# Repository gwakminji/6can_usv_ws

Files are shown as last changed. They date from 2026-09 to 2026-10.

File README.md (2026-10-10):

# 🌊 6can
### by Team Eco Bridge AI

> **"우리 동네 호수를 지키는 작은 눈"**
> AI 무인수상정(USV)으로 지역 수질을 실시간으로 관찰하고, 스스로 반응하는 환경 모니터링 시스템

6can은 인천 지역사회의 수질 환경 문제를 해결하기 위해 팀 **Eco Bridge AI**가 진행한
PBL(Problem-Based Learning) 기반 사회공헌 프로젝트입니다. 무인수상정(USV)이 수면을
직접 순찰하며 수질(탁도·pH·용존산소·수온)을 실시간으로 측정하고, 측정값에 따라
정화 펌프를 제어하도록 설계했습니다. 수질과 위치 데이터는 웹 대시보드에 표시됩니다.

## 📷 활동 사진 및 시연 영상

인천 센트럴파크에서 띄운 수상정, 보트 모습, 지역사회 의견 수집 사진입니다. 사진을 누르면 원본을 볼 수 있습니다.

| 인천 센트럴파크에서 띄운 수상정 | 6can 보트 이미지 | 공원·호수에 관한 지역사회 의견판 |
|---|---|---|
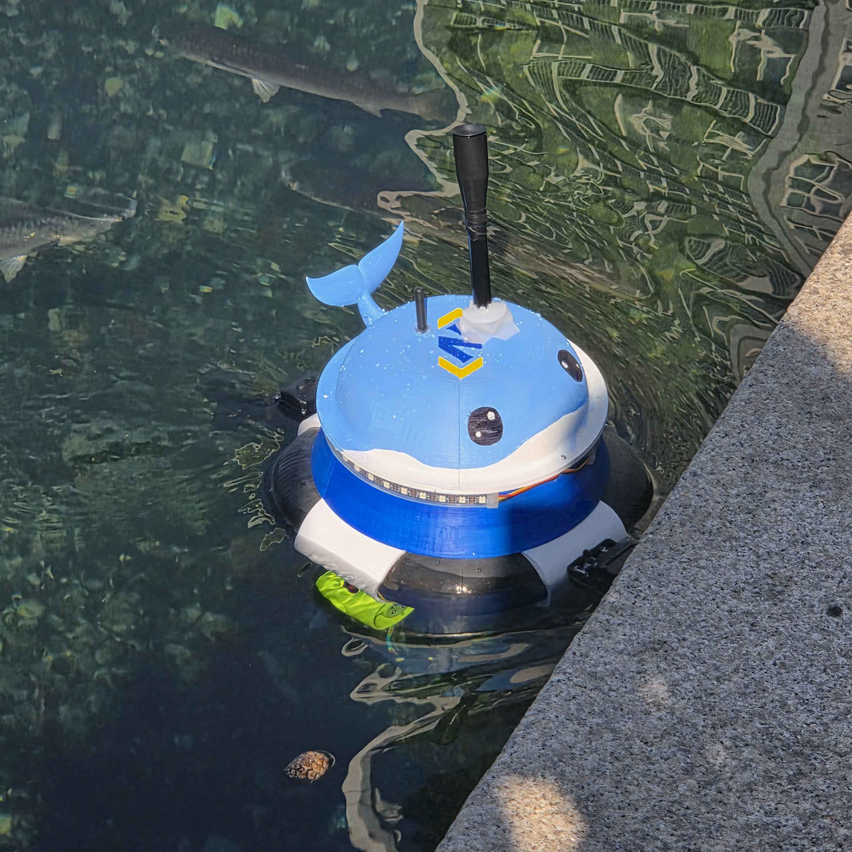
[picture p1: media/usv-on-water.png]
인천 센트럴파크 수면에 떠 있는 파란색 수상정
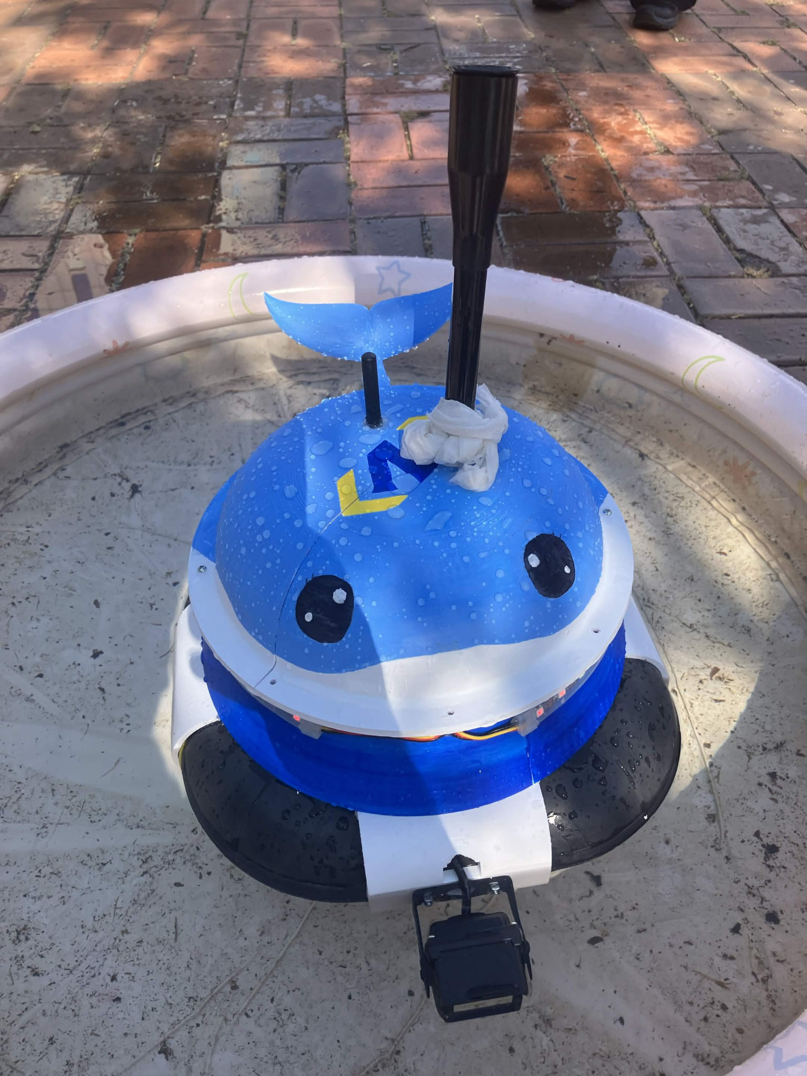
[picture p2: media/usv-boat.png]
파란색 6can 보트의 모습
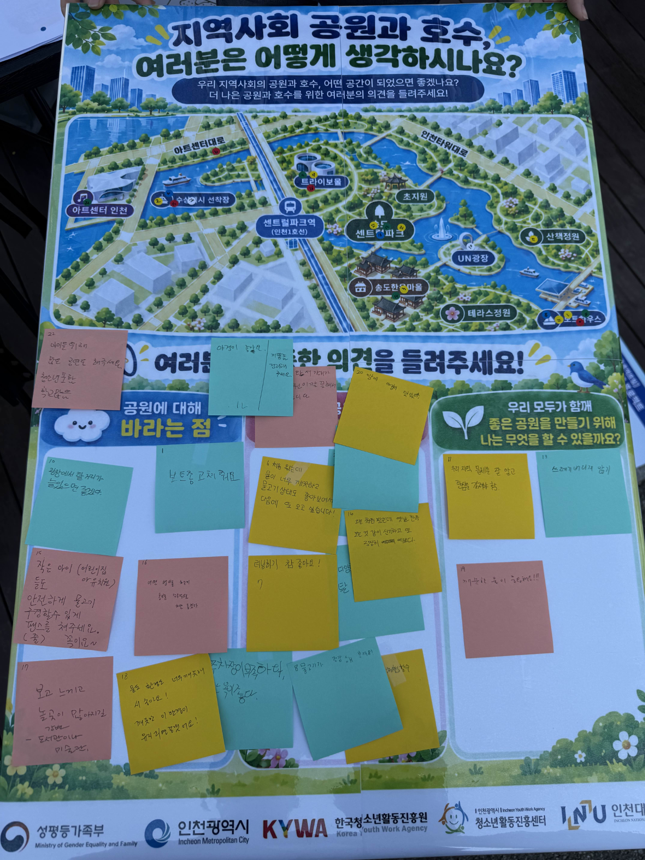
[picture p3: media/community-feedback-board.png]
공원과 호수에 관한 의견이 붙은 게시판
|  |  |  |

**시연 영상:** [인천 센트럴파크에서 수상정이 물을 분사하는 모습 보기 (MP4)](media/usv-water-spray-demo.mp4)

---

## 📌 추진 배경 및 문제 정의

프로젝트는 송도 센트럴파크 호수의 녹조와 부유물 관리 문제를 주제 선정 계기로 삼았습니다.
넓은 수면을 이동하며 수질과 위치를 확인하고, 필요할 때 분수 장치를 작동시키는 방안을 구상했습니다.

인천 지역의 하천·호수는 다음과 같은 구조적인 관리 한계를 안고 있습니다.

| 기존 관리 방식의 한계 | 내용 |
|---|---|
| **낮은 측정 빈도** | 사람이 직접 현장에 나가 정기적으로 샘플을 채취·측정 — 측정 주기 사이의 수질 이상을 놓치기 쉬움 |
| **높은 운영 비용** | 정기 점검마다 인력·출동 비용이 반복적으로 발생 |
| **접근성 사각지대** | 배·선박 없이 접근하기 어려운 구역은 관리 빈도가 더 낮아짐 |
| **시민 체감도 부족** | 수질 데이터가 공개되지 않거나 이해하기 어려운 형태로만 존재해, 환경 문제에 대한 시민 관심으로 이어지기 어려움 |

6can은 이 문제를 "사람이 주기적으로 나가서 재는" 방식에서 "무인선이 상시 관찰하고,
그 결과를 누구나 볼 수 있게 보여주는" 방식으로 바꾸는 것을 목표로 합니다.

---

## 🎯 핵심 목표

- 🌐 **실시간 수질 모니터링** — 탁도, pH, 용존산소, 수온을 무인선이 상시 측정
- 🤖 **자동 반응형 정화** — 측정된 수질 등급에 따라 정화 펌프를 제어하는 기능을 목표로 함
- 🕹️ **원격 조종 지원** — 필요 시 조이스틱으로 무인선을 직접 조종 가능
- 📊 **시민 친화적 시각화** — 웹 대시보드에서 수질 상태와 GPS 미니맵을 확인
- 💸 **저비용 오픈 하드웨어 기반** — 범용 SBC(Arduino UNO Q)·오픈소스 소프트웨어(ROS 2)로 구현해 재현·확장이 쉬운 구조

---

## ⚠️ 작동 특이사항

- 🚤 **배 이동** — 게임 상태와 무관하게 조이스틱으로 항상 조종 가능
- 🔒 **펌프 · 자동/수동 전환 · LED** — 대시보드에서 START를 눌러 게임이 진행 중일 때만 동작 (메인·엔딩 화면에서는 무시됨)
- 🔄 **초기화** — 게임이 시작되거나 끝날 때마다 자동모드는 수동으로, LED는 꺼진 상태로 리셋

---

## 🛠 시스템 아키텍처 및 파트별 역할

6can은 무인선에 탑재되는 **HW(하드웨어 제어) 보드 2대**와, 육상에서 관제하는
**SW/GUI(모니터링·조종) 1대**로 구성됩니다. 보드 간 통신은 ROS 2(DDS)로, 사람이 보는
화면은 웹 브라우저로 분리했습니다.

| 파트 | 보드 | 역할 | 핵심 기술 스택 |
|---|---|---|---|
| 🔧 **HW — 센싱/영상/정화** | B1 (Arduino UNO Q) | 수질·GPS 센서, 수면/수중 카메라, 펌프·LED가 연결된 보드 | ROS 2 Jazzy(Docker), MCU RPC, OpenCV(V4L2), MJPEG |
| 🔧 **HW — 추진** | B2 (Arduino UNO Q) | 추진기만 연결된 별도 보드 | ROS 2 Jazzy(Docker), PWM 모터 드라이버, MCU RPC |
| 💻 **SW/GUI — 관제** | GCS (Raspberry Pi) | 조이스틱 입력 → 조종 명령 변환, 센서/영상 데이터 수신 후 웹 대시보드로 시각화 | ROS 2(네이티브), Python(Flask), HTML5 Canvas, HTTP 폴링·MJPEG 스트리밍 |

**통신 구조**: 보드 사이(B1·B2·GCS)는 ROS 2 DDS 기반 발행/구독(pub-sub)으로 연결되어
있고, GCS는 수신한 최신 상태를 자체 웹 서버(Flask)가 REST 엔드포인트(`/api/state`)로
변환해 브라우저가 200ms 간격으로 폴링합니다. 웹 보트 위치는 `/cmd_vel`에 따라
움직이고 GPS는 미니맵에만 사용됩니다. 카메라 영상은 B1이 MJPEG로 직접 송출해
브라우저가 GCS를 거치지 않고 수신합니다.

**현재 실행 설정 확인 필요:** 펌프·LED는 실제로 B1에 연결돼 있지만,
`actuators.launch.py`는 `actuator_driver_node`를 B2에서 실행합니다. 이 노드는
로컬 MCU RPC를 사용하므로 현재 배선에서 펌프·LED 제어가 가능한지는 확인이 필요합니다.
이번 문서 정리에서는 보드 실행 코드와 자동 실행 스크립트를 변경하지 않았습니다.

### 📡 시스템 구조도

```mermaid
flowchart LR
  JOY([조이스틱]) -->|/joy| J2C
  BROWSER([웹 브라우저 대시보드])
  DIAG[[진단용 · 미구독]]

  subgraph GCS["SW/GUI · Raspberry Pi"]
    J2C[joy_to_cmd_node]
    GUI[gui_main_node]
  end

  subgraph B1S["HW · B1 — 수질·GPS 센서"]
    WQN[water_quality_node]
    GPSN[gps_driver_node]
  end

  subgraph B1C["HW · B1 — 카메라"]
    CAMN[camera_node]
    HVS[http_video_server]
  end

  subgraph B1A["HW · B1 — 실제 펌프·LED 배선"]
    PUMP[펌프·LED MCU]
  end

  subgraph B2["HW · B2 — 실제 추진기 배선 및 현재 실행 설정"]
    THR[thruster_driver_node]
    ACT[actuator_driver_node · 현재 B2에서 실행]
  end

  J2C -->|/cmd_vel| GUI
  J2C -->|/cmd_vel| THR
  J2C -->|/actuator/pump_cmd| GUI
  J2C -->|/actuator/pump_cmd| ACT
  J2C -->|/actuator/auto_mode| GUI
  J2C -->|/actuator/auto_mode| ACT
  GUI -->|/gcs/game_active| J2C
  GUI -->|/actuator/led_cmd| ACT
  ACT -->|/actuator/led_state| GUI

  WQN -->|/water_quality/data| GUI
  WQN -->|/water_quality/data| ACT
  GPSN -->|/gps/fix, /gps/has_fix| GUI
  GPSN -.->|/gps/satellites, /gps/status| DIAG

  CAMN --> HVS
  HVS -. "HTTP :8000 (MJPEG)" .-> BROWSER
  GUI -. "HTTP :8000 (대시보드)" .-> BROWSER

  ACT -->|/actuator/pump_state| GUI
  ACT -.->|로컬 RPC 대상과 실제 배선 불일치 · 확인 필요| PUMP
```

### 🔩 설계 및 실물 하드웨어

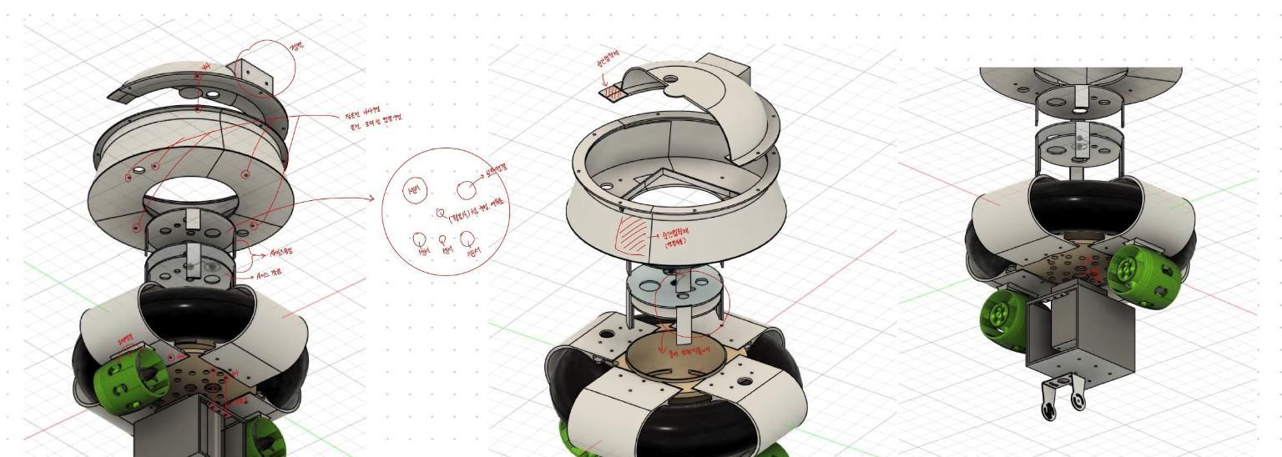
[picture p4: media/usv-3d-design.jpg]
상부 분수 모듈과 구동부를 포함한 수상정 3D 설계 이미지


*수상정 3D 설계 이미지*

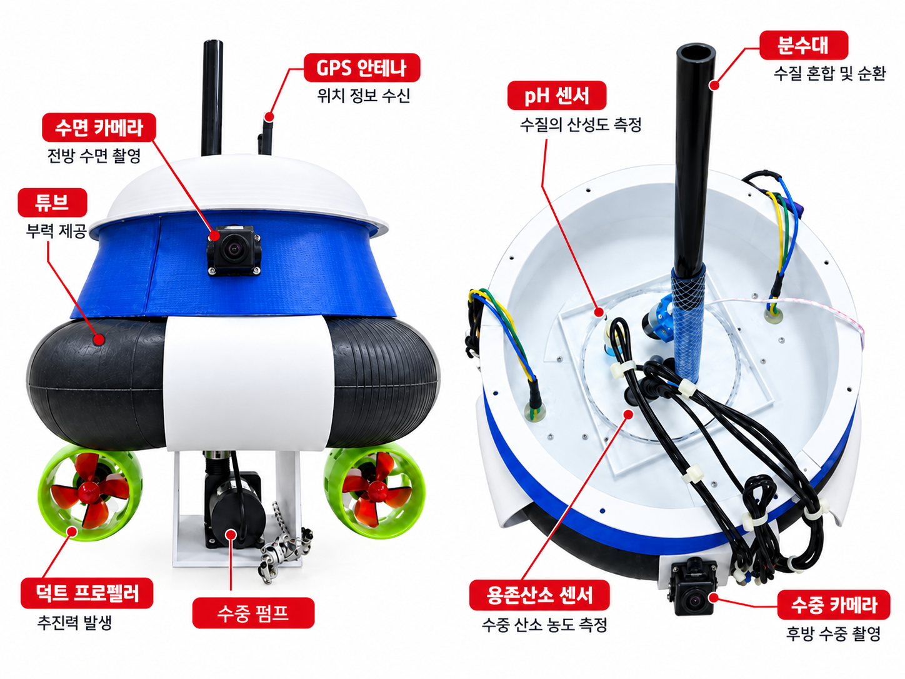
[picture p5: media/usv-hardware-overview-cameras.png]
부력 튜브와 추진기, 펌프, 센서 및 앞쪽 수면 카메라와 뒤쪽 수중 카메라의 위치를 표시한 보트 구성 이미지


---

## 🧪 제작 및 검증 기록

| 단계 | 발표자료에 기록된 내용 |
|---|---|
| 부품 선정 | 교수 자문을 받아 사용 환경과 부품 호환성을 검토 |
| 센서 확인 | 표준용액으로 측정 오차를 확인하고 기준값과 비교 |
| 시스템 통합 | 파트별 작업을 합친 뒤 발생한 호환 문제를 공동 작업으로 점검 |
| 이동성·현장 테스트 | 인천대학교에서 이동성 테스트, 송도 센트럴파크에서 필드 테스트 진행 |

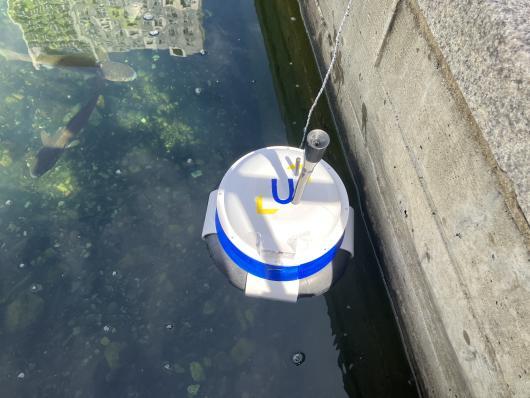
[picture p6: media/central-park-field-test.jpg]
송도 센트럴파크 물 위에 띄운 수상정의 필드 테스트 사진


*송도 센트럴파크 필드 테스트 사진*

---

## 💡 기대 효과

| 효과 | 설명 |
|---|---|
| 🌱 **지역사회 수질 환경 개선** | 상시 순찰형 모니터링으로 수질 이상을 조기에 발견하고, 자동 정화 반응으로 대응 시간을 단축 |
| 💰 **지자체 관리 예산 절감** | 인력 기반 정기 수질 조사의 일부를 무인 자동화로 대체해, 반복적인 출동·인건비 부담을 완화 |
| 📣 **시민 환경 인식 제고** | 그동안 비공개·비정기적이던 수질 데이터를 실시간 시각화로 누구나 접근 가능하게 제공해, 지역 환경 문제에 대한 관심과 참여를 유도 |

---

# 🔧 기술 문서 (개발·운영 가이드)

> 아래는 실제로 이 저장소를 빌드·실행·튜닝할 때 필요한 최소한의 정보만 담았습니다.

## ⚙️ 파라미터 체크리스트 (가장 먼저 확인)

현장/하드웨어가 바뀌면 코드를 고치지 말고 아래 값들만 조정하세요.

| 파라미터 | 위치 | 기본값 | 언제 바꾸나 |
|---|---|---|---|
| `camera_host` | `src/usv_gcs/config/gcs_params.yaml` 또는 `gcs.launch.py` 인자 | `192.168.0.6` (설정 파일 예시) | B1 보드의 실제 IP로 변경 |
| `linear_axis` / `angular_axis` / `angular_scale` | `gcs.launch.py` 인자 | `1` / `0` / `-1.0` | 실제 조이스틱 축 번호·방향이 다를 때 |
| `pump_button` / `auto_button` | `gcs.launch.py` 인자 | `0`(A) / `1`(B) | 조이스틱 버튼 배치가 다를 때 |
| `linear_ramp_rate` / `angular_ramp_rate` | `src/usv_gcs/usv_gcs/joy_to_cmd_node.py`의 `declare_parameter` 기본값 (launch 인자 아님 — 일부러 여기 한 곳만 유지) | `0.2` / `0.4` | 조이스틱을 급히 꺾어도 속도가 얼마나 천천히 올라갈지 조정할 때 |
| `GACHA_GAMEPAD_BUTTON_INDEX` | `dashboard_html.py` 상수 | `2`(Y, 추정치) | 실기기로 검증 후 정확한 값으로 |
| `max_pwm` | `actuators.launch.py` 인자 | `255` | 실제 모터 드라이버 PWM 사양 확정 후 |
| `bad_below` / `good_above` / `*_manual_hold_s` | `actuators.launch.py` 인자 | `40.0` / `60.0` / `60.0`초 | 실측 수질 범위·자동/수동 우선 시간 조정 시 |
| `BACK_GAMEPAD_BUTTON_INDEX` | `dashboard_html.py` 상수 | `8`(추정치) | 실기기로 검증 후 정확한 값으로 |
| `SHOW_SURFACE_CAM` / `SHOW_UNDERWATER_CAM` | `dashboard_html.py` 상단 상수 | `true` / `true` | 수면/수중 카메라 박스를 각각 껐다 켜려면 `false`/`true`로 |
| `surface_device` / `underwater_device` | `camera_streaming.launch.py` 인자 | `/dev/video2` / `/dev/video3` | USB 카메라 재연결로 장치 번호가 바뀌었을 때 (`v4l2-ctl --list-devices`로 확인) |

`dashboard_html.py`처럼 코드 상수를 바꾼 경우, 파일만 고치고 끝이 아니라
**`gui_main_node`를 재시작**해야 브라우저에 반영됩니다 (HTML/JS가 프로세스 시작 시
메모리에 올라가는 구조라서 `--symlink-install`로도 핫리로드는 안 됩니다).

---

## 🚀 실행 방법

```bash
# 1. B1 (센서 + 카메라; 펌프·LED는 B1에 배선됨)
./start_b1.sh

# 2. B2 (추진기; 현재 액추에이터 제어 노드도 함께 시작됨)
cd src/usv_actuators && ./start_actuators.sh

# 3. GCS (관제) — 조이스틱 연결 후
sudo apt install ros-jazzy-joy
colcon build --symlink-install --packages-select usv_gcs
source install/setup.bash
ros2 launch usv_gcs gcs.launch.py
```

브라우저 주소: `http://<GCS_IP>:8000` (GCS에서 열면 `http://localhost:8000`)

B1/B2는 `install_*_autostart.sh`로 부팅 자동 실행을 등록해두면 이후엔 전원만 넣으면
됩니다. 개별 보드 빌드/자동 실행 세부 설정, 컨테이너 구성은 `src/<패키지>/` 아래
`start_*.sh`, `systemd/*.service`를 참고하세요.

---

## 🕹️ 조이스틱 구성

하나의 컨트롤러가 **① 실제 보트 조종(ROS)** 과 **② 웹 대시보드 미니 모니터링 화면
조작(브라우저)** 을 처리합니다. 이동(전진/후진/회전)은 웹 대시보드 상태와 무관하게
항상 되지만, **펌프·자동/수동 전환·LED는 대시보드에서 START를 눌러 게임이 진행 중일
때만** 실제로 동작합니다 (메인 화면·엔딩 화면에서는 버튼을 눌러도 무시됨). 게임이
시작되거나 끝나는 순간마다 자동모드는 수동으로, LED는 꺼진 상태로 초기화됩니다.

| 구분 | 조작 | 동작 |
|---|---|---|
| 보트 조종 (ROS `/joy`) | 왼쪽 스틱 좌/우 · 상/하 | 좌우 회전 · 전진/후진 (`/cmd_vel`) — 게임 상태 무관, 항상 동작 |
| 보트 조종 (ROS `/joy`) | A 버튼 | 펌프 on/off 토글 (게임 진행 중일 때만) |
| 보트 조종 (ROS `/joy`) | B 버튼 | 자동/수동 제어 모드 토글 (게임 진행 중일 때만) |
| 웹 화면 (브라우저 Gamepad API) | Start 버튼 | 대시보드 화면 시작 |
| 웹 화면 (브라우저 Gamepad API) | X 버튼 | LED on/off 토글 (게임 진행 중일 때만) |
| 웹 화면 (브라우저 Gamepad API) | Y 버튼 | 화면 내 상호작용(뽑기) 실행 |
| 웹 화면 (브라우저 Gamepad API) | Back 버튼 | 초기 화면으로 복귀 |

버튼 인덱스를 실기기로 확인하려면 브라우저 콘솔(F12)에서:
```js
setInterval(() => console.log(navigator.getGamepads()[0]?.buttons.map((b,i)=>b.pressed?i:null).filter(v=>v!==null)), 300)
```

---

## 📎 참고

- 인터페이스 계약(토픽 이름/타입), 보드별 상세 빌드 옵션, Docker/systemd 구성은 각
  패키지(`src/usv_sensors`, `src/usv_actuators`, `src/camera_streaming`, `src/usv_gcs`)의
  launch 파일과 스크립트 주석에 정리되어 있습니다.
- 현재 `usv_actuators` 패키지는 추진기 노드와 펌프·LED 제어 노드를 모두 B2에서
  시작합니다. 실제 배선은 B1에 펌프·LED, B2에 추진기만 연결된 구성입니다.

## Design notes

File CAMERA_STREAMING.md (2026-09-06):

# 카메라 스트리밍 (Surface / Underwater) → HTTP:8000

수면(surface) 카메라와 수중(underwater) 카메라 영상을 ROS 2 토픽으로 발행하고,
HTTP MJPEG 스트림으로 변환해 내보내는 파이프라인입니다. 브라우저 UI(화면
구성)는 이 프로젝트의 범위가 아니며, 스트림 URL을 제공하는 데까지만 다룹니다.

전부 **자체 작성한 가벼운 Python/OpenCV 코드**로 만들었습니다 (`usb_cam`,
`web_video_server` ROS 패키지는 쓰지 않습니다 — 두 패키지가 boost-dev,
ffmpeg-dev, GTK/Qt 등을 끌고 와서 이 보드(9.8GB 디스크)에서는 이미지 빌드가
디스크 부족으로 계속 실패했습니다. 대신 `opencv-python-headless`(pip, GUI
의존성 없음) 하나만 써서 이미지 용량을 947MB → 1.1GB 수준으로 유지했습니다).

## 아키텍처

```text
surface 카메라(USB) ──┐
                      ├─ camera_node(OpenCV) ──▶ /camera/surface/image_raw ────┐
underwater 카메라(USB)┘                          /camera/underwater/image_raw ─┤
                                                                                ▼
                                                                  http_video_server
                                                              http://<보드IP>:8000
```

- `camera_node`가 `cv2.VideoCapture`로 두 카메라를 열어 `sensor_msgs/msg/Image`를
  초당 15프레임(기본값)으로 계속 발행합니다. (정지 이미지 한 장이 아니라
  연속 프레임 스트림입니다.) 카메라가 없거나 열기 실패하면 죽지 않고 계속
  재시도만 합니다.
- `http_video_server`가 그 두 토픽을 구독해 `cv2.imencode`로 JPEG 변환 후,
  Python 표준 `http.server`로 MJPEG(`multipart/x-mixed-replace`) 스트림을
  내보냅니다.
- ROS 2 Jazzy는 UNO Q Linux 위 **별도의** Docker 컨테이너
  (`camera_streaming_container`, 이미지 `camera_streaming_image`)에서 실행됩니다.
  같은 B1 보드에서 도는 수질/GPS 컨테이너(`usv_sensors_container` / `usv_sensors_image`)와
  이름이 완전히 분리되어 있어 서로 절대 충돌하지 않습니다. `--network host`라서
  컨테이너 안에서 연 포트가 보드의 실제 포트로 바로 노출되고, 같은
  `ROS_DOMAIN_ID=0`을 쓰므로 두 컨테이너의 ROS 2 토픽은 호스트 네트워크
  위에서 서로 정상적으로 보입니다(간섭 없이 공존). B1 보드를 통째로 올릴 땐
  레포 루트의 `start_b1.sh`가 이 컨테이너와 `usv_sensors` 컨테이너를 순서대로
  띄운다 (README.md 3항 참고).

## 패키지 위치

```text
6can_usv_ws/src/camera_streaming/
├── Dockerfile
├── requirements.txt            # opencv-python-headless, numpy
├── start_camera_streaming.sh   # 이미지 빌드(최초 1회) → 컨테이너 실행
├── install_autostart.sh        # (선택) 부팅 시 자동 실행 등록 (systemd/camera-streaming.service)
├── package.xml
├── setup.py / setup.cfg
├── camera_streaming/
│   ├── camera_node.py         # OpenCV 캡처 → ROS 2 Image 발행
│   └── http_video_server.py   # ROS 2 Image 구독 → HTTP MJPEG
└── launch/camera_streaming.launch.py
```

## ROS 2 토픽

| 토픽 | 타입 | 설명 |
|---|---|---|
| `/camera/surface/image_raw` | `sensor_msgs/msg/Image` | 표면 카메라 원본 프레임 (bgr8) |
| `/camera/underwater/image_raw` | `sensor_msgs/msg/Image` | 수중 카메라 원본 프레임 (bgr8) |

## HTTP 엔드포인트 (기본 포트 8000)

| URL | 설명 |
|---|---|
| `http://<보드IP>:8000/` | 현재 스트리밍 가능한 토픽 목록 페이지 |
| `http://<보드IP>:8000/stream?topic=/camera/surface/image_raw` | 표면 카메라 **실시간 영상** (MJPEG, `<img>` 태그로 그대로 재생됨) |
| `http://<보드IP>:8000/stream?topic=/camera/underwater/image_raw` | 수중 카메라 **실시간 영상** |
| `http://<보드IP>:8000/snapshot?topic=/camera/surface/image_raw` | 표면 카메라 정지 이미지 한 장(jpeg) |
| `http://<보드IP>:8000/snapshot?topic=/camera/underwater/image_raw` | 수중 카메라 정지 이미지 한 장(jpeg) |

화면을 여러 개 동시에 띄우고 싶으면 `<img src="...">` 태그를 토픽별로 나란히
두면 됩니다. 서버가 커넥션마다 별도 스레드로 처리해서 동시 스트리밍에
문제없습니다.

```html
<img src="http://<보드IP>:8000/stream?topic=/camera/surface/image_raw">
<img src="http://<보드IP>:8000/stream?topic=/camera/underwater/image_raw">
```

## launch 인자 (기본값)

| 이름 | 기본값 | 설명 |
|---|---|---|
| `surface_device` | `/dev/video2` | 표면 카메라 V4L2 장치 경로 |
| `underwater_device` | `/dev/video3` | 수중 카메라 V4L2 장치 경로 |
| `port` | `8000` | HTTP 포트 |

기본값 `/dev/video2`, `/dev/video3`는 보드 내장 Venus 인코더/디코더가 이미
`/dev/video0`, `/dev/video1`을 쓰고 있어서 USB 카메라가 보통 2번부터 잡힐
것이라는 **예상값**입니다.

## 실제 USB 카메라 연결 후 할 일

1. 카메라 2대를 **UNO Q 보드**의 USB 포트에 연결합니다 (노트북이 아니라 보드에
   꽂아야 이 파이프라인이 잡을 수 있습니다).
2. 실제로 잡힌 장치 번호를 확인합니다.
   ```bash
   v4l2-ctl --list-devices
   ```
3. 기본값(`/dev/video2`, `/dev/video3`)과 다르면 `start_camera_streaming.sh`가
   실행하는 `ros2 launch` 줄에 인자를 추가하고 다시 실행합니다 (스크립트 자체는
   그대로 두고, 그 안의 `ros2 launch camera_streaming camera_streaming.launch.py`
   줄만 아래처럼 인자를 붙이면 됩니다):
   ```bash
   cd 6can_usv_ws/src/camera_streaming
   ./start_camera_streaming.sh
   # 장치 번호가 다르면: 컨테이너 안에서
   #   ros2 launch camera_streaming camera_streaming.launch.py \
   #       surface_device:=/dev/videoX underwater_device:=/dev/videoY
   ```
4. 정상 동작 확인:
   ```bash
   docker logs camera_streaming_container --tail 50
   curl http://localhost:8000/
   ```

## 부팅 시 자동 실행

```bash
cd 6can_usv_ws/src/camera_streaming
./install_autostart.sh
```

`systemd/camera-streaming.service`를 설치해 부팅 시 `start_camera_streaming.sh`를
자동 실행하도록 등록합니다 (컨테이너 자체도 `--restart unless-stopped`라 Docker
데몬이 살아있는 한 다시 켜집니다). B1 보드의 다른 컨테이너(`usv_sensors_container`)와
이름/이미지가 겹치지 않으므로 서로의 자동 실행에 영향을 주지 않습니다. 두 컨테이너를
한 번에 등록하려면 레포 루트의 `install_b1_autostart.sh`를 쓰세요.

## 현재 알려진 상태 (이 문서 작성 시점)

- 보드에 실제 USB 카메라가 아직 연결되어 있지 않습니다 (`lsusb` 결과 없음).
  `/dev/video0`, `/dev/video1`은 카메라가 아니라 SoC 내장 Venus
  인코더/디코더입니다.
- 파이프라인 자체는 합성 프레임(테스트 rclpy 퍼블리셔)으로 끝까지
  검증했습니다: `http_video_server`가 두 토픽 모두 인식했고, `/snapshot`이
  두 토픽 다 정확한 640x480 유효 JPEG를 반환했으며, `/stream`이 발행 중
  4초 동안 다수의 MJPEG 프레임 경계를 내보내 **연속 영상 스트림**임을
  확인했습니다.
- 실제 카메라가 없는 동안 `camera_node`는 계속 재시도하며 조용히 대기합니다.
  로그에 `could not open /dev/videoN, will retry`가 반복해서 보이는 것이
  정상입니다.
- 다른 팀의 `ros_jazzy_container`(수질/GPS)는 이 작업 내내 정상 가동
  상태였고, 앞으로도 이 컨테이너와는 이름/포트가 겹치지 않습니다.

## 확인 명령어 모음

```bash
# 컨테이너 로그
docker logs camera_streaming_container --tail 50

# 토픽 확인
docker exec camera_streaming_container bash -lc \
  'source /opt/ros/jazzy/setup.bash && source /ros2_ws/install/setup.bash && ros2 topic list | grep camera'

# HTTP 응답 확인
curl http://localhost:8000/
curl -o /tmp/surface.jpg "http://localhost:8000/snapshot?topic=/camera/surface/image_raw"
```

## 문제 해결

| 증상 | 확인할 것 |
|---|---|
| `/camera/...` 토픽이 안 보임 | `v4l2-ctl --list-devices`로 실제 장치 번호 확인 후 launch 인자 수정 |
| `/snapshot`이 404 | 아직 그 토픽에 프레임이 한 번도 안 들어온 상태 — 카메라 연결/토픽 발행 확인 |
| 포트 8000 응답 없음 | `ss -tlnp \| grep 8000`으로 다른 프로세스가 포트를 쓰고 있는지 확인 |
| 컨테이너가 계속 재시작됨 | `docker logs camera_streaming_container`로 어느 노드에서 나는 오류인지 확인 |

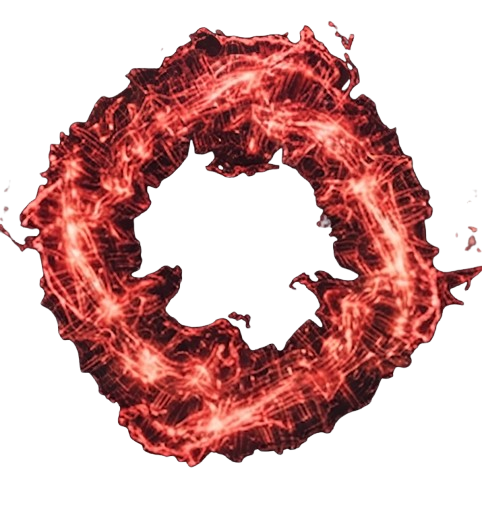
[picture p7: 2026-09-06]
src/usv_gcs/web/red.png

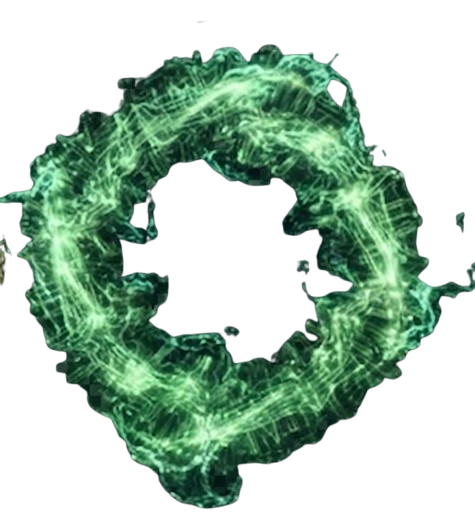
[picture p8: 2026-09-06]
src/usv_gcs/web/green.png

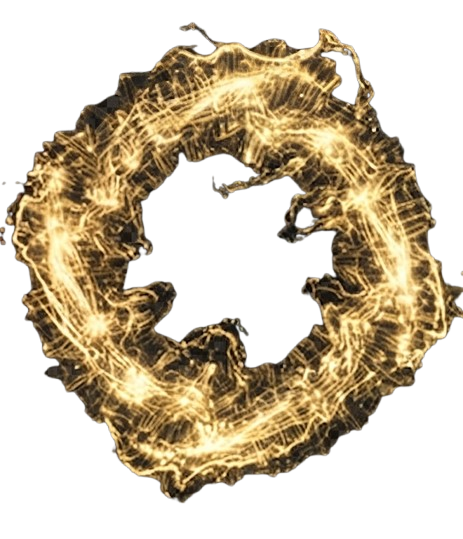
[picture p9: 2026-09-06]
src/usv_gcs/web/yellow.png

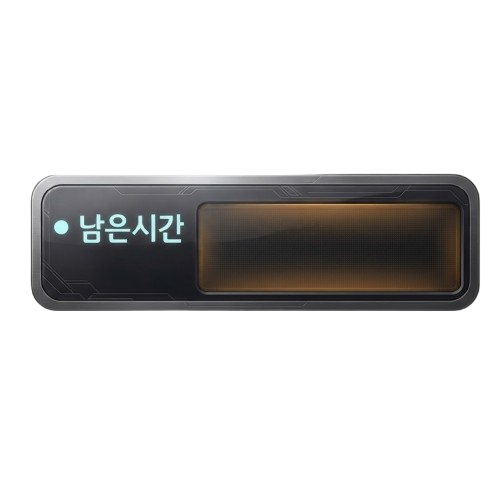
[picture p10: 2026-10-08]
src/usv_gcs/web/time.png

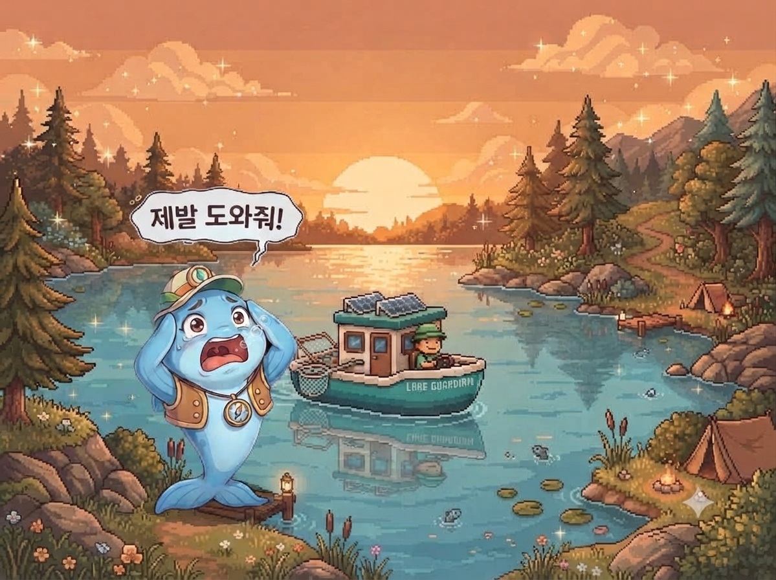
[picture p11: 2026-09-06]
src/usv_gcs/web/mainstart.png

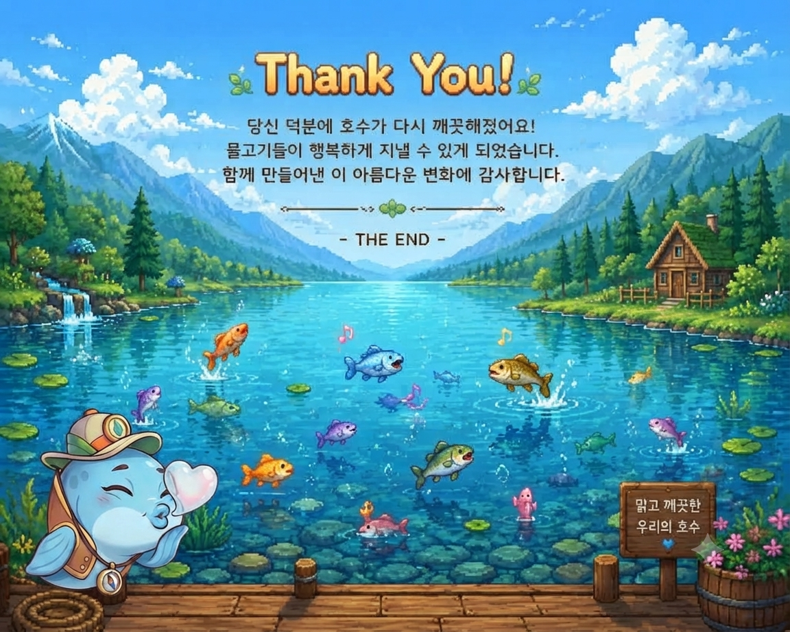
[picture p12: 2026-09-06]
src/usv_gcs/web/ending.png

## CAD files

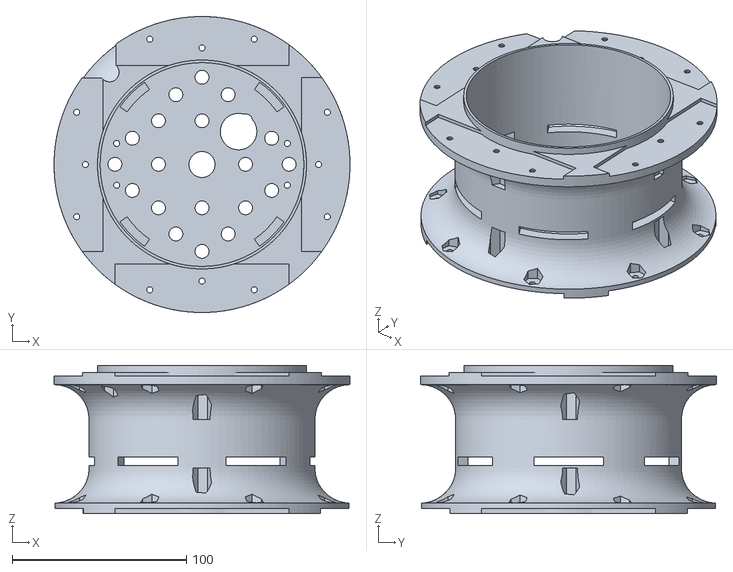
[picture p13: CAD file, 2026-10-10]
stl_file/main_body.stl
170.0 x 170.0 x 85.0

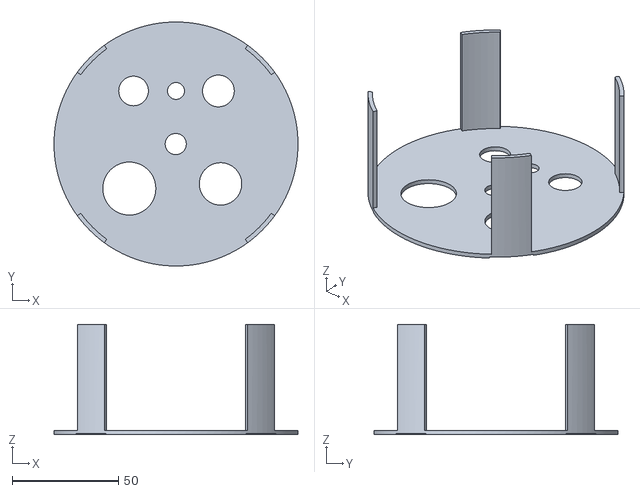
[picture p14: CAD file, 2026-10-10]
stl_file/p1.stl
115.0 x 115.0 x 52.0

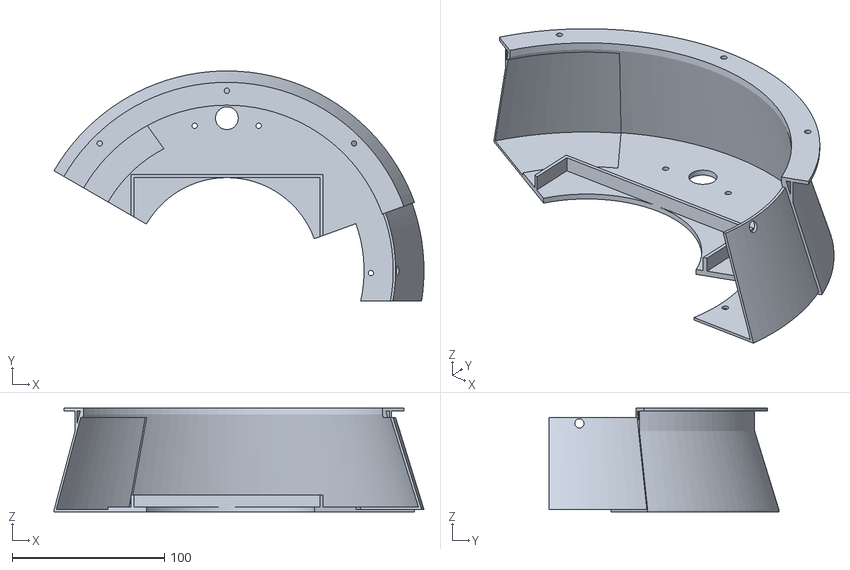
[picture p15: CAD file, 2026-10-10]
stl_file/low_body_3.stl
242.8 x 151.0 x 68.0

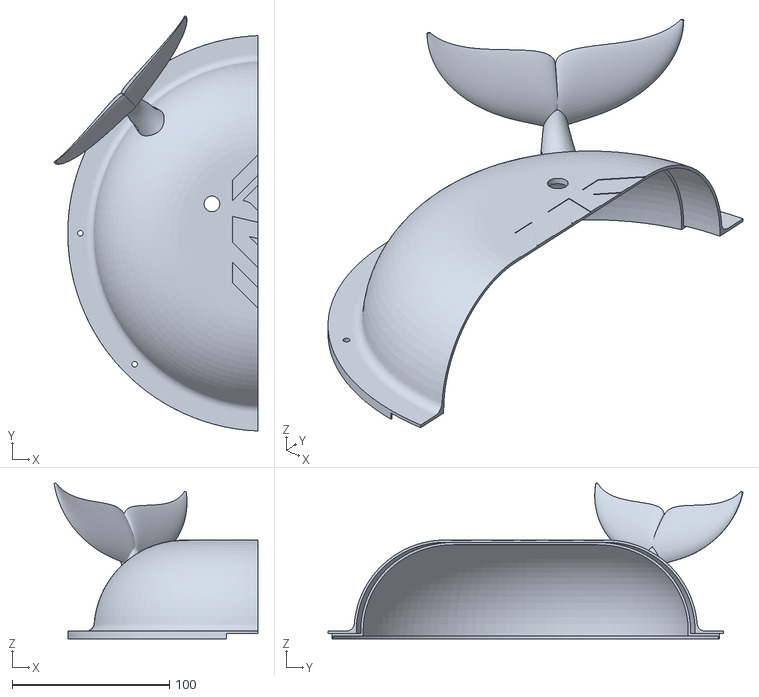
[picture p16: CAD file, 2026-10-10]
stl_file/whale.stl
129.7 x 264.3 x 99.2

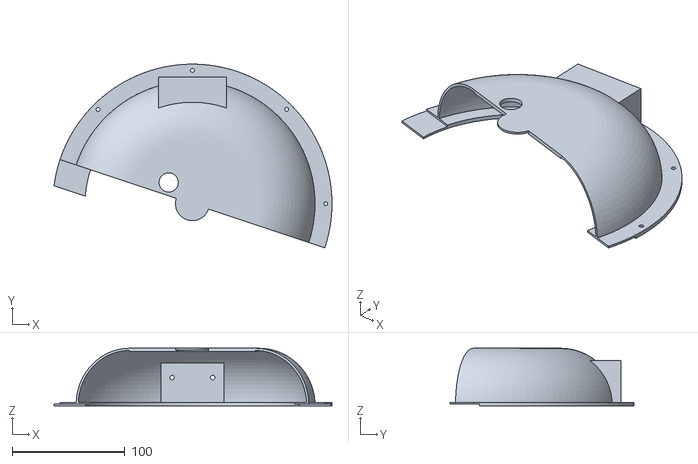
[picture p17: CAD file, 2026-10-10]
stl_file/dom.stl
246.0 x 162.6 x 51.0

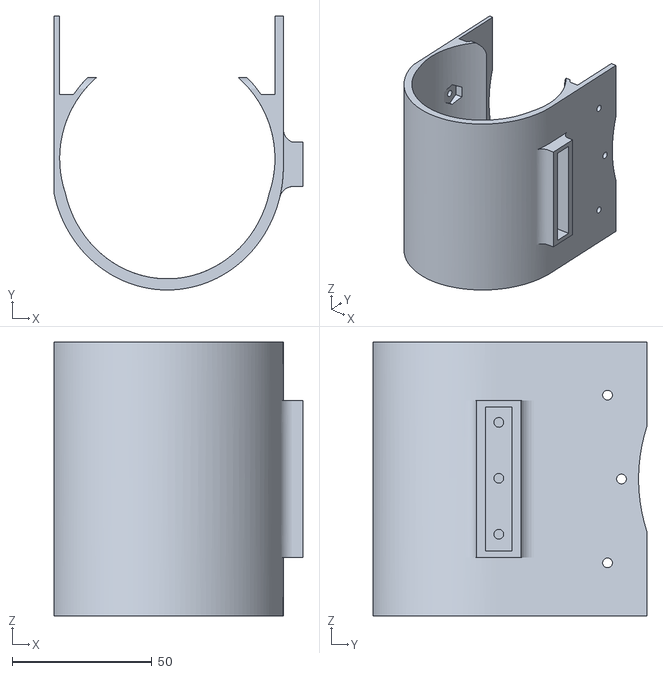
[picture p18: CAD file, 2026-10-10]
stl_file/cover_2.stl
89.0 x 98.0 x 98.0

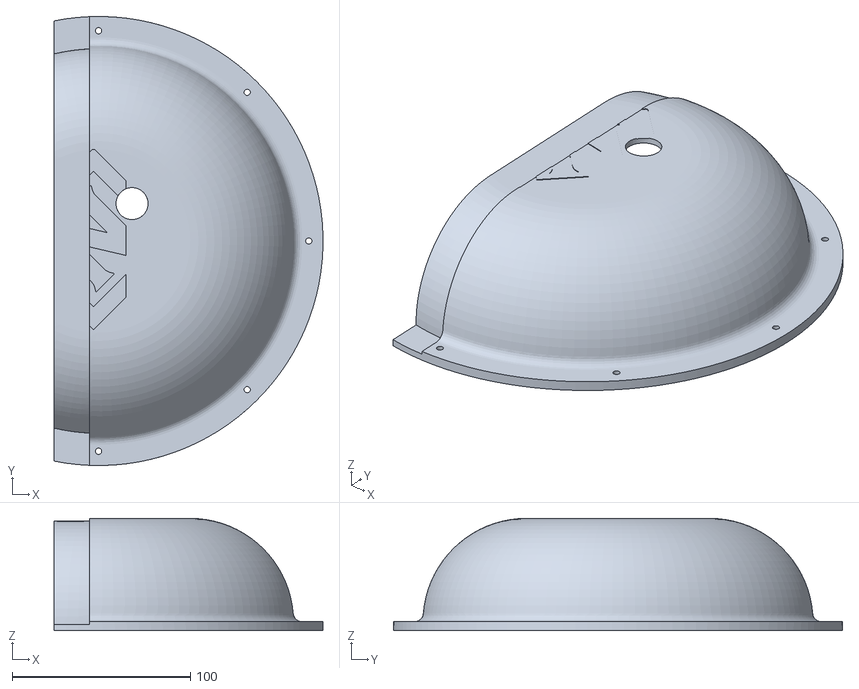
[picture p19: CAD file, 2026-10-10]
stl_file/dom_5.stl
151.0 x 252.0 x 63.0

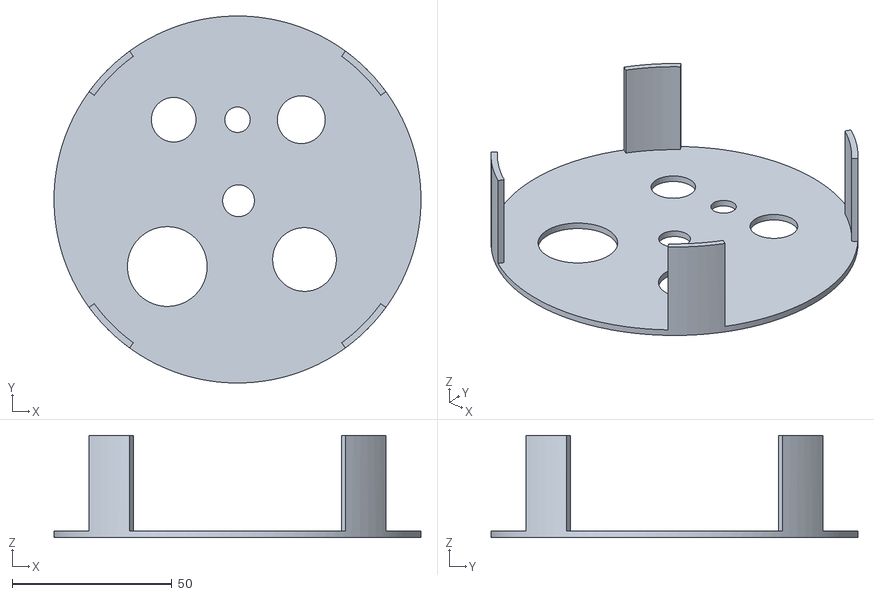
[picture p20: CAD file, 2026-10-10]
stl_file/p3.stl
115.0 x 115.0 x 32.0

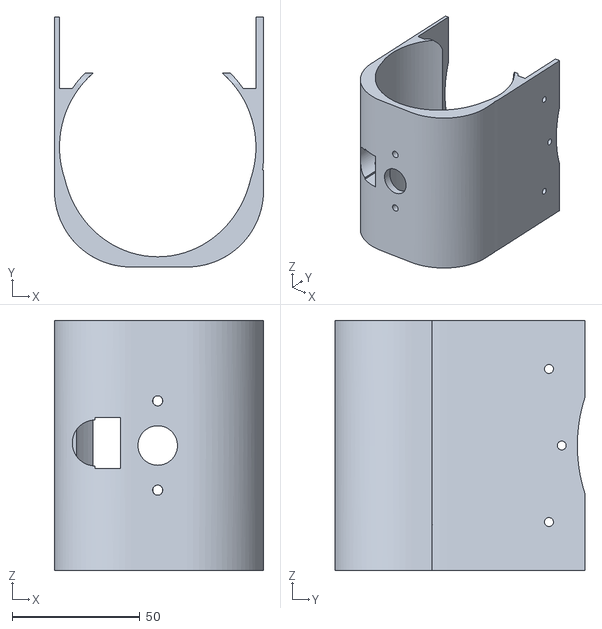
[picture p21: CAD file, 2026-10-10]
stl_file/cover_4.stl
82.0 x 98.0 x 98.0

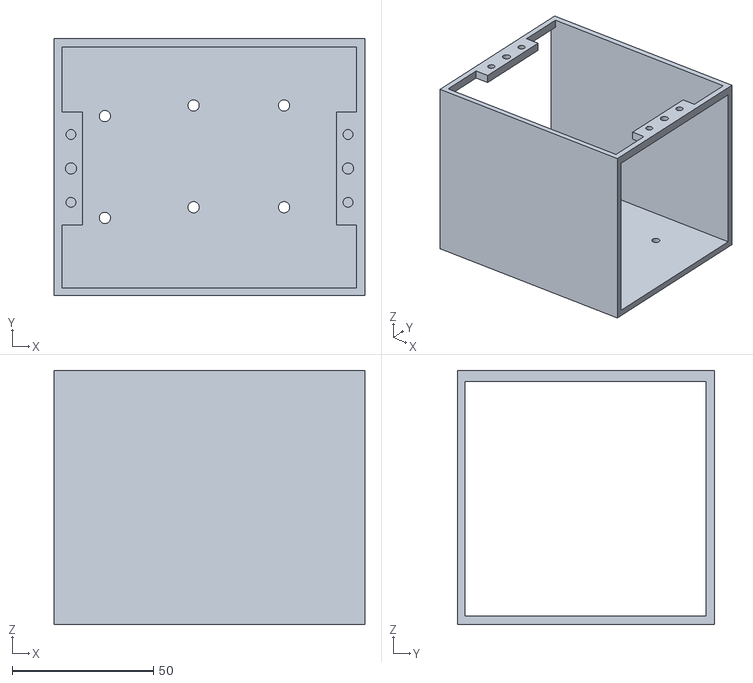
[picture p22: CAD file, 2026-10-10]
stl_file/pump_cover.stl
110.0 x 91.0 x 90.0

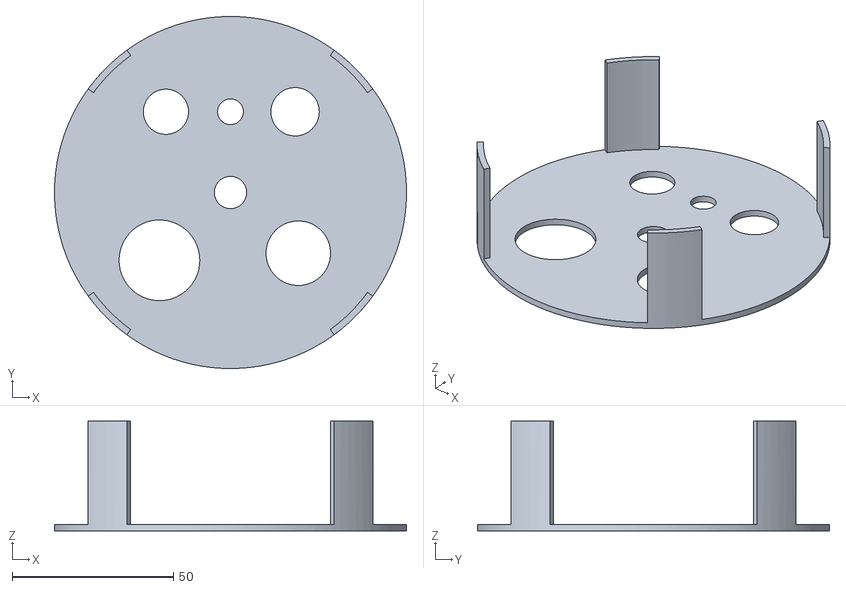
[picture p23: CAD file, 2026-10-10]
stl_file/p2.stl
109.0 x 109.0 x 34.0

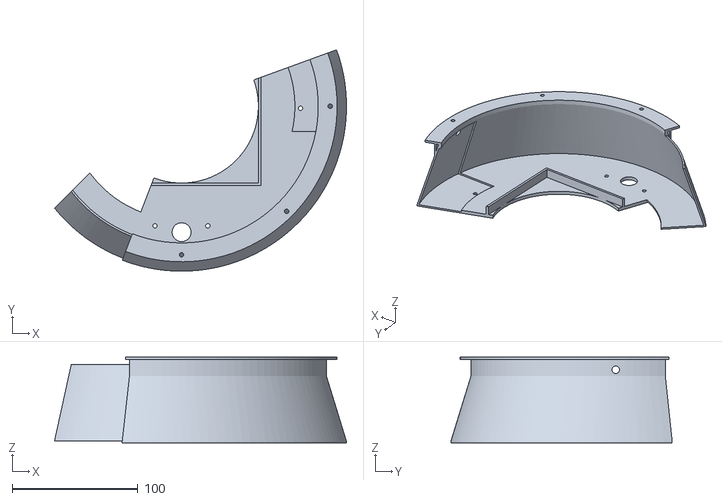
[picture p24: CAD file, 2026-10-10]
stl_file/low_body_1.stl
231.9 x 175.8 x 68.0

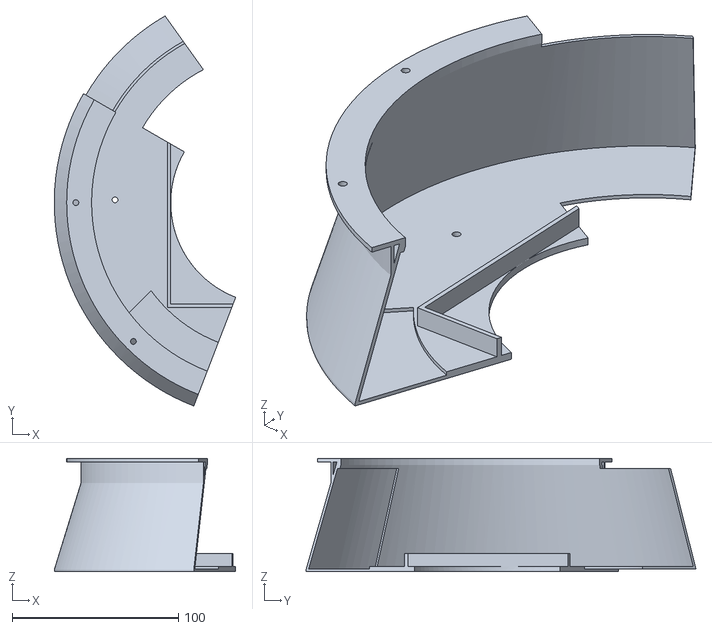
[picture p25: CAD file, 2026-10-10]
stl_file/low_body_2.stl
109.0 x 234.4 x 68.0

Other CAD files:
stl_file/pumpcover.stl

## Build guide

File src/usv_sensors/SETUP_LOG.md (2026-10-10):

# usv_sensors (B1 보드) 실행 기록

`6can_usv_ws` 저장소를 클론한 뒤 `src/usv_sensors`를 이 보드(UNO Q, B1)에서
처음 실행하면서 겪은 과정과 조치 내역 정리.

## 0. 클론

```bash
git clone https://github.com/gwakminji/6can_usv_ws
cd 6can_usv_ws/src/usv_sensors
```

## 1. 최초 실행 시도 — `./start_sensors.sh`

Docker 이미지(`usv_sensors_image`) 빌드는 성공(약 10분, `cv_bridge` 의존성 때문에
apt 패키지가 많음). 이어서 아래 에러로 실패:

```
[1] Starting Arduino App (water_quality + GPS sketch)...
app path is not valid: stat /home/arduino/ArduinoApps/usv_sensors: no such file or directory
```

**원인**: `arduino-app-cli app start`는 App 이름이 아니라 **경로**를 받는데,
클론한 저장소가 App Lab이 앱을 찾는 `~/ArduinoApps/` 아래에 없었음.

**조치**: 심볼릭 링크 생성 (실제 파일은 클론한 저장소에만 존재, 양쪽 어디서 수정해도 동일):

```bash
ln -s /home/arduino/6can_usv_ws/src/usv_sensors /home/arduino/ArduinoApps/usv_sensors
```

## 2. 재실행 — `icon` 에러

```
icon "USV" is not a valid single emoji
```

**원인**: `app.yaml`의 `icon: "USV"`가 텍스트라서 App Lab이 거부.

**조치**: `app.yaml`의 `icon`을 `"🚤"`로 수정.

## 3. 재실행 — `python/main.py` 누락

```
main python file missing from app
```

**원인**: 저장소에 App Lab 필수 진입점인 `python/main.py`가 아예 없었음
(ROS 2 쪽 개발에 집중하느라 빠진 것으로 보임). MCU 스케치는
`get_water_quality`/`get_gps`를 `Bridge.provide`로 이미 노출하고 있음.

**조치**: 선행 프로젝트 `waterqualityros2/python/main.py`와 동일한 패턴으로
`python/main.py` 신규 작성 — `Bridge.call`로 두 값을 읽어 콘솔에 출력만 함
(실제 ROS 2 로직은 Docker 컨테이너가 같은 `arduino-router.sock`으로 직접 통신).

## 4. 재실행 — 스케치 컴파일 에러

```
sketch.ino:346:6: error: variable or field 'addAdcSample' declared void
sketch.ino:346:20: error: 'AdcAccumulator' was not declared in this scope
...
```

**원인**: Arduino 빌더가 함수 프로토타입을 소스 상단(include/define 블록 바로
뒤)에 자동 삽입하는데, `struct AdcAccumulator`가 그보다 한참 아래(346번째 줄
근처)에 정의돼 있어서 프로토타입 삽입 시점엔 타입이 안 보임.

**조치**: 구조체를 별도 헤더로 분리해서 include 블록 안에 넣음 —
`sketch/adc_accumulator.h` 신규 생성 후 `sketch.ino` 상단에 `#include`,
기존 인라인 struct 정의는 삭제.

## 5. 재실행 — 성공

```
✓ App "usv_sensors" started successfully
[5] usv_sensors nodes started (water_quality_node, gps_driver_node, camera_node).
```

확인된 사항:
- App Lab: `user:usv_sensors` → `running`
- `docker ps`: `usv_sensors_container` 정상 기동
- `ros2 topic list` (컨테이너 안):
  `/water_quality/*`, `/gps/*`,
  `/camera/surface,underwater/image_raw`(별도 `camera_streaming` 컨테이너),
  `/parameter_events`, `/rosout` 전부 정상 발행

## 6. 값 검증

- **temp_c / do_mg_l**: 실내 상온 기준 그럴듯한 값, 변화도 자연스러움 → 정상.
- **ph (~12.54, 거의 고정)**, **turbidity/clarity (~92%, 거의 고정)**: 강알칼리
  수준이라 비정상적으로 보였으나, 원인은 **pH/탁도 캘리브레이션 미실시** +
  프로브가 버퍼 용액이 아니라 실온 공기/물에 있었기 때문으로 확인.
  `sketch.ino`의 `PH7_VOLTAGE`/`PH4_VOLTAGE`/`PH_CALIBRATION_T`,
  `CLEAR_WATER_VOLTAGE`/`VERY_TURBID_VOLTAGE` 상수가 하드코딩값이라 실제
  버퍼 용액(pH 4/7)으로 캘리브레이션하면 정상 범위로 나올 것.
- **GPS (fix=false, satellites=0)**: 실내라 위성 신호 미수신 — 예상된 정상 동작.
- **camera**: USB 카메라 미연결 상태라 아직 검증 안 함(`camera_streaming` 컨테이너
  자체는 이전부터 떠 있음).

## 파일 위치 요약

| 항목 | 경로 |
|---|---|
| 클론 저장소 루트 | `/home/arduino/6can_usv_ws/` |
| usv_sensors 패키지 | `6can_usv_ws/src/usv_sensors/` |
| App Lab 심볼릭 링크 | `/home/arduino/ArduinoApps/usv_sensors` → 위 경로 |
| 수정: `app.yaml` | `icon` 필드 변경 |
| 신규: `python/main.py` | App Lab 진입점 |
| 수정: `sketch/sketch.ino` | `AdcAccumulator` struct 제거 |
| 신규: `sketch/adc_accumulator.h` | `AdcAccumulator` struct 이동 |
| Docker 이미지 | `usv_sensors_image` |
| Docker 컨테이너 | `usv_sensors_container` |
| App Lab 앱 ID | `user:usv_sensors` |

## 실행/확인 명령 모음

```bash
# 시작 (저장소 경로에서)
cd /home/arduino/6can_usv_ws/src/usv_sensors
./start_sensors.sh
./install_autostart.sh          # 선택: 부팅 자동 실행 등록 (아직 미실행)

# App 로그 / 상태 (심볼릭 링크 경로로)
arduino-app-cli app logs    /home/arduino/ArduinoApps/usv_sensors --follow
arduino-app-cli app stop    /home/arduino/ArduinoApps/usv_sensors
arduino-app-cli app restart /home/arduino/ArduinoApps/usv_sensors

# ROS 2 토픽 확인
docker exec usv_sensors_container bash -c \
  "source /opt/ros/jazzy/setup.bash && source /ros2_ws/install/setup.bash && ros2 topic list"

# 컨테이너 로그
docker logs -f usv_sensors_container
```

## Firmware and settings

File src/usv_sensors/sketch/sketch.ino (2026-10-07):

#include <Arduino.h>
#include <Arduino_RouterBridge.h>
#include <OneWire.h>
#include <SPI.h>
#include <math.h>
#include "adc_accumulator.h"

#define TEMP_PIN 4
#define PH_PIN A1
#define DO_PIN A5
#define TURBIDITY_PIN A0

// B2 보드 usv_actuators 스케치에서 가져온 분수 펌프 릴레이 제어.
// NEROMART RELAY-M1(CH1)-5V, 옵토커플러 입력이라 Active LOW.
const int PUMP_PIN = 7;
const bool PUMP_ACTIVE_LOW = true;

// LED: WS2812B 15개 x 2줄, 두 스트립 DIN 모두 D11(SPI2 MOSI)에 연결.
// NeoPixel 라이브러리는 show() 동안 인터럽트를 꺼서(~0.45ms) Bridge 시리얼
// (lpuart1, DMA/FIFO 없음) 바이트가 유실되고 MCU 전체가 멈췄다.
// SPI 하드웨어로 파형을 만들면 인터럽트를 끌 필요가 없다.
// SPI 2.5MHz(400ns/비트)에서 WS2812 1비트 = SPI 4비트: 1 → 1100, 0 → 1000
// SPI가 인터럽트 방식이라 바이트 사이에 간격이 생기고, 그동안 MOSI는 다음 바이트의
// 첫 비트를 내보낸다. 첫 비트가 1이면 HIGH가 늘어나 0이 1로 읽힘(전부 흰색).
// → 비트열을 1비트 밀어서 바이트가 항상 0으로 시작하고 0으로 끝나게 한다:
//   바이트 = 0 1 a 0 0 1 b 0  (a, b = WS2812 비트 2개). 간격은 LOW만 늘린다.
#define NUMPIXELS 15
#define LED_DATA_PIN 11                // D11 = SPI2 MOSI
const int LED_BRIGHTNESS = 50;
const uint32_t LED_SPI_HZ = 3000000;   // STM32 분주로 실제 2.5MHz가 선택됨
// 앞뒤 0 패딩은 짧게 (4바이트 = 12.8us). 리셋(래치)에 필요한 280us 이상 LOW는
// 전송 후 GPIO LOW 고정 + 프레임 간 최소 간격(LED_LATCH_US)으로 보장한다.
// SPI 전송 시간이 짧을수록 Bridge 시리얼 바이트 유실 위험이 줄어든다.
#define LED_RESET_BYTES 4
#define LED_LATCH_US 300
uint32_t ledLastShowUs = 0;
uint8_t ledSpiBuf[LED_RESET_BYTES + NUMPIXELS * 12 + LED_RESET_BYTES];
uint8_t ledPixels[NUMPIXELS][3];       // WS2812B 와이어 순서: G, R, B

#define ADC_BITS 12
#define ADC_MAX 4095.0
#define ADC_REFERENCE_V 3.3
#define ADC_REFERENCE_MV 3300.0
#define SAMPLE_COUNT 40

#define PH7_BUFFER_VALUE 7.00
#define PH4_BUFFER_VALUE 4.00

#define PH7_VOLTAGE 1.142
#define PH4_VOLTAGE 0.888

#define PH_CALIBRATION_T 25.47

#define DO_CAL_V 1505.0
#define DO_CAL_T 25.4

#define TURBIDITY_DIVIDER_RATIO 1.5

#define CLEAR_WATER_VOLTAGE 4.810
#define VERY_TURBID_VOLTAGE 0.140

OneWire oneWire(TEMP_PIN);

byte temperatureAddress[8];
bool temperatureSensorFound = false;

const uint16_t DO_TABLE[41] = {
  14460, 14220, 13820, 13440, 13090,
  12740, 12420, 12110, 11810, 11530,
  11260, 11010, 10770, 10530, 10300,
  10080,  9860,  9660,  9460,  9270,
   9080,  8900,  8730,  8570,  8410,
   8250,  8110,  7960,  7820,  7690,
   7560,  7430,  7300,  7180,  7070,
   6950,  6840,  6730,  6630,  6530,
   6410
};

// =================================================
// NEO-M8N GPS (UART / NMEA-0183)
// =================================================

String gpsLine = "";
bool gpsFix = false;
bool gpsParserOk = false;
uint8_t gpsSatellites = 0;
double gpsLatitude = NAN;
double gpsLongitude = NAN;
unsigned long gpsBytesReceived = 0;
unsigned long gpsSentencesReceived = 0;
unsigned long gpsChecksumErrors = 0;
unsigned long gpsLastSentenceMs = 0;

#define GPS_FIX_TIMEOUT_MS 5000


String nmeaField(
  const String &line,
  uint8_t fieldIndex
)
{
  int start = 0;
  uint8_t currentField = 0;

  for (int i = 0; i <= line.length(); i++)
  {
    if (i == line.length() || line.charAt(i) == ',')
    {
      if (currentField == fieldIndex)
        return line.substring(start, i);

      start = i + 1;
      currentField++;
    }
  }

  return "";
}


bool isNmeaType(
  const String &line,
  const char *suffix
)
{
  return line.length() >= 6 &&
         line.charAt(0) == '$' &&
         line.substring(3, 6) == suffix;
}


bool hasValidNmeaChecksum(const String &line)
{
  int separator = line.indexOf('*');

  if (line.length() < 7 || line.charAt(0) != '$' ||
      separator < 0 || separator + 2 >= line.length())
    return false;

  uint8_t calculated = 0;
  for (int i = 1; i < separator; i++)
    calculated ^= (uint8_t)line.charAt(i);

  String checksumText = line.substring(separator + 1, separator + 3);
  char *end = nullptr;
  unsigned long received = strtoul(checksumText.c_str(), &end, 16);

  return end != checksumText.c_str() && *end == '\0' &&
         received <= 0xFF && calculated == (uint8_t)received;
}


double nmeaCoordinateToDegrees(
  const String &raw,
  char hemisphere
)
{
  if (raw.length() < 4)
    return NAN;

  double value = raw.toDouble();
  int degrees = (int)(value / 100.0);
  double minutes = value - degrees * 100.0;
  double result = degrees + minutes / 60.0;

  if (hemisphere == 'S' || hemisphere == 'W')
    result = -result;

  return result;
}


void parseNmeaLine(const String &line)
{
  if (!hasValidNmeaChecksum(line))
  {
    gpsChecksumErrors++;
    return;
  }

  gpsLastSentenceMs = millis();

  // Accept GP, GN, and other valid NMEA talker IDs.
  if (isNmeaType(line, "GGA"))
  {
    int fixQuality = nmeaField(line, 6).toInt();
    gpsSatellites = (uint8_t)nmeaField(line, 7).toInt();

    if (fixQuality == 0)
      gpsFix = false;
    else
    {
      String rawLat = nmeaField(line, 2);
      String ns = nmeaField(line, 3);
      String rawLon = nmeaField(line, 4);
      String ew = nmeaField(line, 5);

      gpsLatitude = nmeaCoordinateToDegrees(
        rawLat,
        ns.length() ? ns.charAt(0) : 'N'
      );
      gpsLongitude = nmeaCoordinateToDegrees(
        rawLon,
        ew.length() ? ew.charAt(0) : 'E'
      );
      gpsFix = !isnan(gpsLatitude) && !isnan(gpsLongitude);
    }
  }
  else if (isNmeaType(line, "RMC"))
  {
    gpsFix = nmeaField(line, 2) == "A";

    if (gpsFix)
    {
      String rawLat = nmeaField(line, 3);
      String ns = nmeaField(line, 4);
      String rawLon = nmeaField(line, 5);
      String ew = nmeaField(line, 6);

      gpsLatitude = nmeaCoordinateToDegrees(
        rawLat,
        ns.length() ? ns.charAt(0) : 'N'
      );

      gpsLongitude = nmeaCoordinateToDegrees(
        rawLon,
        ew.length() ? ew.charAt(0) : 'E'
      );
    }
  }
}


void serviceGps()
{
  while (Serial1.available() > 0)
  {
    char c = Serial1.read();
    gpsBytesReceived++;

    if (c == '\n' || c == '\r')
    {
      if (gpsLine.length() > 0)
      {
        if (gpsLine.charAt(0) == '$')
          gpsSentencesReceived++;

        parseNmeaLine(gpsLine);
        gpsLine = "";
      }
    }
    else if (c >= 32 && c <= 126)
    {
      if (gpsLine.length() < 120)
        gpsLine += c;
      else
        gpsLine = "";
    }
  }

  if (gpsLastSentenceMs > 0 &&
      millis() - gpsLastSentenceMs > GPS_FIX_TIMEOUT_MS)
    gpsFix = false;
}


void waitWhileReadingGps(unsigned long durationMs)
{
  unsigned long startedAt = millis();

  while (millis() - startedAt < durationMs)
  {
    serviceGps();
    delay(1);
  }
}


bool runGpsParserSelfTest()
{
  bool savedFix = gpsFix;
  uint8_t savedSatellites = gpsSatellites;
  double savedLatitude = gpsLatitude;
  double savedLongitude = gpsLongitude;
  unsigned long savedLastSentenceMs = gpsLastSentenceMs;
  unsigned long savedChecksumErrors = gpsChecksumErrors;

  parseNmeaLine(
    "$GNGGA,123519,3723.2475,N,12701.2345,E,1,08,0.9,10.0,M,0.0,M,,*55"
  );
  parseNmeaLine(
    "$GNRMC,123519,A,3723.2475,N,12701.2345,E,0.0,0.0,010126,,,A*63"
  );

  bool passed = gpsFix &&
                gpsSatellites == 8 &&
                fabs(gpsLatitude - 37.3874583) < 0.00001 &&
                fabs(gpsLongitude - 127.020575) < 0.00001;

  gpsFix = savedFix;
  gpsSatellites = savedSatellites;
  gpsLatitude = savedLatitude;
  gpsLongitude = savedLongitude;
  gpsLastSentenceMs = savedLastSentenceMs;
  gpsChecksumErrors = savedChecksumErrors;

  return passed;
}


bool findTemperatureSensor()
{
  oneWire.reset_search();

  while (oneWire.search(temperatureAddress))
  {
    if (OneWire::crc8(temperatureAddress, 7)
        != temperatureAddress[7])
      continue;

    if (temperatureAddress[0] == 0x28)
      return true;
  }

  return false;
}


bool startTemperatureConversion()
{
  if (!temperatureSensorFound)
    return false;

  if (!oneWire.reset())
    return false;

  oneWire.select(temperatureAddress);
  oneWire.write(0x44, 1);

  return true;
}


float readTemperatureResult()
{
  byte data[9];

  if (!oneWire.reset())
    return NAN;

  oneWire.select(temperatureAddress);
  oneWire.write(0xBE);

  for (int i = 0; i < 9; i++)
    data[i] = oneWire.read();

  if (OneWire::crc8(data, 8) != data[8])
    return NAN;

  int16_t raw =
    ((int16_t)data[1] << 8) | data[0];

  return raw / 16.0;
}


void addAdcSample(
  AdcAccumulator &accumulator,
  int pin
)
{
  // Discard one reading after changing ADC channels so the multiplexer
  // and sample-and-hold circuit can settle.
  analogRead(pin);
  delayMicroseconds(200);

  int value = analogRead(pin);

  accumulator.sum += value;

  if (value < accumulator.minValue)
    accumulator.minValue = value;

  if (value > accumulator.maxValue)
    accumulator.maxValue = value;
}


double trimmedAdcAverage(
  const AdcAccumulator &accumulator
)
{
  return (
    (double)accumulator.sum -
    accumulator.minValue -
    accumulator.maxValue
  ) / (SAMPLE_COUNT - 2);
}


void readWaterQualityInputs(
  float &temperature,
  double &phADC,
  double &doADC,
  double &turbidityADC
)
{
  AdcAccumulator phSamples;
  AdcAccumulator doSamples;
  AdcAccumulator turbiditySamples;

  unsigned long conversionStartedAt = millis();
  bool temperatureConversionStarted =
    startTemperatureConversion();

  // Collect all three analog channels during the DS18B20 conversion.
  // The channels are interleaved rather than waiting 800 ms per sensor.
  for (int i = 0; i < SAMPLE_COUNT; i++)
  {
    addAdcSample(phSamples, PH_PIN);
    addAdcSample(doSamples, DO_PIN);
    addAdcSample(turbiditySamples, TURBIDITY_PIN);
    waitWhileReadingGps(18);
  }

  unsigned long elapsed = millis() - conversionStartedAt;
  if (temperatureConversionStarted && elapsed < 750)
    waitWhileReadingGps(750 - elapsed);

  temperature = temperatureConversionStarted
    ? readTemperatureResult()
    : NAN;
  phADC = trimmedAdcAverage(phSamples);
  doADC = trimmedAdcAverage(doSamples);
  turbidityADC = trimmedAdcAverage(turbiditySamples);
}


float adcToVoltage(double adcValue)
{
  return adcValue *
         ADC_REFERENCE_V /
         ADC_MAX;
}


float adcToMillivolts(double adcValue)
{
  return adcValue *
         ADC_REFERENCE_MV /
         ADC_MAX;
}


float calculatePH(
  float voltage,
  float temperature
)
{
  if (isnan(temperature))
    return NAN;

  float voltageDifference =
    PH4_VOLTAGE -
    PH7_VOLTAGE;

  if (fabs(voltageDifference) < 0.001)
    return NAN;

  float calibrationSlope =
    (PH4_BUFFER_VALUE -
     PH7_BUFFER_VALUE)
    /
    voltageDifference;

  float temperatureSlope =
    calibrationSlope *
    (
      (PH_CALIBRATION_T + 273.15)
      /
      (temperature + 273.15)
    );

  return
    PH7_BUFFER_VALUE +
    temperatureSlope *
    (voltage - PH7_VOLTAGE);
}


float calculateDO(
  float voltageMv,
  float temperature
)
{
  if (isnan(temperature))
    return NAN;

  int temperatureIndex =
    constrain(
      (int)round(temperature),
      0,
      40
    );

  float saturationVoltage =
    DO_CAL_V +
    35.0 *
    (
      temperatureIndex -
      DO_CAL_T
    );

  if (saturationVoltage <= 0.0)
    return NAN;

  return
    voltageMv *
    DO_TABLE[temperatureIndex]
    /
    saturationVoltage
    /
    1000.0;
}


float calculateCleanliness(
  float voltage
)
{
  float cleanliness =
    (
      voltage -
      VERY_TURBID_VOLTAGE
    )
    /
    (
      CLEAR_WATER_VOLTAGE -
      VERY_TURBID_VOLTAGE
    )
    *
    100.0;

  return constrain(
    cleanliness,
    0.0,
    100.0
  );
}


String getCleanlinessLevel(
  float value
)
{
  if (value >= 80.0)
    return "very_clear";

  if (value >= 60.0)
    return "clear";

  if (value >= 40.0)
    return "normal";

  if (value >= 20.0)
    return "turbid";

  return "very_turbid";
}


String floatToJson(
  float value,
  int digits
)
{
  if (isnan(value))
    return "null";

  return String(
    value,
    digits
  );
}


// =================================================
// Linux/ROS에서 호출할 함수
// =================================================

int set_pump(bool on)
{
  digitalWrite(
    PUMP_PIN,
    (on ^ PUMP_ACTIVE_LOW) ? HIGH : LOW
  );

  return 1;
}


// show()는 색이 바뀔 때만 호출하고, 무지개는 애니메이션 없이
// LED마다 다른 색을 한 번만 칠한다.
bool ledRainbowOn = false;
int ledR = -1, ledG = -1, ledB = -1;

void ledShow()
{
  int k = 0;
  memset(ledSpiBuf, 0, LED_RESET_BYTES);
  k += LED_RESET_BYTES;

  for (int i = 0; i < NUMPIXELS; i++)
  {
    for (int c = 0; c < 3; c++)
    {
      uint8_t v = (ledPixels[i][c] * (LED_BRIGHTNESS + 1)) >> 8;

      for (int j = 7; j >= 0; j -= 2)
      {
        uint8_t a = (v >> j) & 1;
        uint8_t b = (v >> (j - 1)) & 1;
        ledSpiBuf[k++] = 0b01000010 | (a << 5) | (b << 1);
      }
    }
  }

  memset(ledSpiBuf + k, 0, LED_RESET_BYTES);

  while (micros() - ledLastShowUs < LED_LATCH_US)
    delayMicroseconds(10);

  SPI.begin();  // D11을 SPI(MOSI)로 되돌림
  SPI.beginTransaction(SPISettings(LED_SPI_HZ, MSBFIRST, SPI_MODE0));
  SPI.transfer(ledSpiBuf, sizeof(ledSpiBuf));
  SPI.endTransaction();

  // SPI가 꺼지면 MOSI가 LOW로 유지되지 않아 색이 깨졌다.
  // 전송 사이에는 GPIO LOW로 고정 → LED가 리셋(래치)을 확실히 받는다.
  pinMode(LED_DATA_PIN, OUTPUT);
  digitalWrite(LED_DATA_PIN, LOW);
  ledLastShowUs = micros();
}

void ledSetPixel(int i, int r, int g, int b)
{
  ledPixels[i][0] = g;
  ledPixels[i][1] = r;
  ledPixels[i][2] = b;
}

void applyLed(int r, int g, int b)
{
  if (r == ledR && g == ledG && b == ledB)
    return;

  ledR = r;
  ledG = g;
  ledB = b;

  for (int i = 0; i < NUMPIXELS; i++)
    ledSetPixel(i, r, g, b);

  ledShow();
}

int set_actuator_led(int r, int g, int b)
{
  // 무지개 중에는 단색 명령을 무시한다 (끄려면 set_led_rainbow(false)).
  if (ledRainbowOn)
    return 0;

  applyLed(r, g, b);
  return 1;
}

void hueToRgb(float hue, int &r, int &g, int &b)
{
  float h = hue * 6.0;
  int i = (int)h;
  float f = h - i;
  float q = 1.0 - f;
  float fr, fg, fb;

  if      (i == 0) { fr = 1.0; fg = f;   fb = 0.0; }
  else if (i == 1) { fr = q;   fg = 1.0; fb = 0.0; }
  else if (i == 2) { fr = 0.0; fg = 1.0; fb = f;   }
  else if (i == 3) { fr = 0.0; fg = q;   fb = 1.0; }
  else if (i == 4) { fr = f;   fg = 0.0; fb = 1.0; }
  else             { fr = 1.0; fg = 0.0; fb = q;   }

  r = round(fr * 255);
  g = round(fg * 255);
  b = round(fb * 255);
}

int set_led_rainbow(bool on)
{
  if (!on)
  {
    ledRainbowOn = false;
    applyLed(0, 0, 0);
    return 1;
  }

  if (ledRainbowOn)
    return 1;
  ledRainbowOn = true;

  // 스트립 길이만큼 빨강→보라 무지개를 고정으로 칠한다.
  for (int i = 0; i < NUMPIXELS; i++)
  {
    int r, g, b;
    hueToRgb((float)i / NUMPIXELS, r, g, b);
    ledSetPixel(i, r, g, b);
  }

  ledShow();

  ledR = ledG = ledB = -1;  // 다음 단색 명령이 반드시 적용되도록
  return 1;
}


String get_water_quality()
{
  unsigned long measurementStartedAt = millis();
  float temperature;
  double phADC;
  double doADC;
  double turbidityADC;

  readWaterQualityInputs(
    temperature,
    phADC,
    doADC,
    turbidityADC
  );

  float phVoltage =
    adcToVoltage(phADC);

  float ph =
    calculatePH(
      phVoltage,
      temperature
    );

  float doVoltageMv =
    adcToMillivolts(doADC);

  float dissolvedOxygen =
    calculateDO(
      doVoltageMv,
      temperature
    );

  float turbidityA0Voltage =
    adcToVoltage(
      turbidityADC
    );

  float turbidityVoltage =
    turbidityA0Voltage *
    TURBIDITY_DIVIDER_RATIO;

  float clarity =
    calculateCleanliness(
      turbidityVoltage
    );

  String level =
    getCleanlinessLevel(
      clarity
    );


  String json = "{";

  json += "\"ms\":";
  json += String(millis());

  json += ",\"measurement_ms\":";
  json += String(millis() - measurementStartedAt);

  json += ",\"temp_c\":";
  json += floatToJson(
    temperature,
    2
  );

  json += ",\"ph\":";
  json += floatToJson(
    ph,
    2
  );

  json += ",\"do_mg_l\":";
  json += floatToJson(
    dissolvedOxygen,
    2
  );

  json +=
    ",\"turbidity_voltage_v\":";

  json += floatToJson(
    turbidityVoltage,
    3
  );

  json += ",\"clarity_pct\":";

  json += floatToJson(
    clarity,
    1
  );

  json +=
    ",\"clarity_level\":\"";

  json += level;

  json += "\"}";

  return json;
}


String get_gps()
{
  serviceGps();

  String json = "{";

  json += "\"ms\":";
  json += String(millis());

  json += ",\"parser_ok\":";
  json += gpsParserOk ? "true" : "false";

  json += ",\"fix\":";
  json += gpsFix ? "true" : "false";

  json += ",\"satellites\":";
  json += String(gpsSatellites);

  json += ",\"latitude\":";
  if (gpsFix && !isnan(gpsLatitude))
    json += String(gpsLatitude, 7);
  else
    json += "null";

  json += ",\"longitude\":";
  if (gpsFix && !isnan(gpsLongitude))
    json += String(gpsLongitude, 7);
  else
    json += "null";

  json += ",\"bytes\":";
  json += String(gpsBytesReceived);

  json += ",\"sentences\":";
  json += String(gpsSentencesReceived);

  json += ",\"checksum_errors\":";
  json += String(gpsChecksumErrors);

  json += ",\"last_sentence_age_ms\":";
  if (gpsLastSentenceMs > 0)
    json += String(millis() - gpsLastSentenceMs);
  else
    json += "null";

  json += "}";

  return json;
}


void setup()
{
  pinMode(PUMP_PIN, OUTPUT);
  set_pump(false);

  // 부팅 직후 스트립 전체를 초기화해 첫 칸만 켜진 채 남지 않게 한다.
  SPI.begin();
  applyLed(0, 0, 0);

  Serial1.begin(9600);

  analogReadResolution(
    ADC_BITS
  );

  temperatureSensorFound =
    findTemperatureSensor();

  gpsParserOk =
    runGpsParserSelfTest();

  Bridge.begin();

  Bridge.provide(
    "get_water_quality",
    get_water_quality
  );

  Bridge.provide(
    "get_gps",
    get_gps
  );

  Bridge.provide(
    "set_pump",
    set_pump
  );

  // LED는 loop()와 같은 스레드에서 처리 (provide_safe).
  Bridge.provide_safe(
    "set_actuator_led",
    set_actuator_led
  );

  Bridge.provide_safe(
    "set_led_rainbow",
    set_led_rainbow
  );
}


void loop()
{
  serviceGps();
}

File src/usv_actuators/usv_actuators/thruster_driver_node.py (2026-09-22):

#!/usr/bin/env python3
"""thruster_driver_node — usv_actuators 패키지 (B2 보드).

구독: /cmd_vel [geometry_msgs/msg/Twist]
Direct Bridge RPC 호출 방식으로 MCU 스케치('set_thruster_pwm') 직접 제어.
"""

import time

import rclpy
from rclpy.node import Node
from geometry_msgs.msg import Twist

from .bridge import Bridge
from .telemetry import bounded_integer


# ============================================================
# Thruster 설정
# ============================================================

NEUTRAL_PWM = 1487

# ESC deadband
DEADBAND = 35

# 최대 출력 변화량
MAX_DELTA = 50

# PWM ramp
STEP_US = 150

# 정/역방향 전환 시 중립 유지 시간
REVERSE_PAUSE = 0.3

# /cmd_vel timeout
CMD_TIMEOUT = 0.5


# ============================================================
# 추진기 방향 설정
#
# 중요:
# LEFT  = CCW 추진기
# RIGHT = CW 추진기
#
# 현재 문제 해결을 위해:
#   왼쪽은 정상 방향
#   오른쪽만 PWM 방향 반전
# ============================================================

LEFT_REVERSED = False
RIGHT_REVERSED = True


class ThrusterDriverNode(Node):

    def __init__(self):
        super().__init__('thruster_driver_node')

        # ----------------------------------------------------
        # /cmd_vel subscriber
        # ----------------------------------------------------
        self.cmd_sub = self.create_subscription(
            Twist,
            '/cmd_vel',
            self.on_cmd_vel,
            10
        )

        # 현재 PWM
        self.cur_left = NEUTRAL_PWM
        self.cur_right = NEUTRAL_PWM

        # 목표 PWM
        self.target_left = NEUTRAL_PWM
        self.target_right = NEUTRAL_PWM

        # 정/역방향 변경 시 중립 유지
        self.hold_until = 0.0

        # 마지막 명령 수신 시간
        self.last_cmd_time = time.monotonic()

        # 20 Hz control loop
        self.timer = self.create_timer(
            0.05,
            self.control_loop
        )

        self.get_logger().info(
            'Thruster Driver Node Started '
            '(Direct Bridge RPC Mode)'
        )

        self.get_logger().info(
            f'Thruster direction: '
            f'LEFT_REVERSED={LEFT_REVERSED}, '
            f'RIGHT_REVERSED={RIGHT_REVERSED}'
        )

    # ========================================================
    # /cmd_vel callback
    # ========================================================

    def on_cmd_vel(self, msg: Twist):

        self.last_cmd_time = time.monotonic()

        # ----------------------------------------------------
        # 입력 범위 제한
        # ----------------------------------------------------
        linear = max(
            -1.0,
            min(1.0, msg.linear.x)
        )

        angular = max(
            -1.0,
            min(1.0, msg.angular.z)
        )

        # ----------------------------------------------------
        # Differential thrust mixing
        #
        # 전진:
        # linear > 0, angular = 0
        #
        # 좌회전 / 우회전:
        # angular 값으로 좌우 출력 차등
        # ----------------------------------------------------
        left_raw = linear - angular
        right_raw = linear + angular

        # ----------------------------------------------------
        # -1.0 ~ +1.0 범위로 정규화
        # ----------------------------------------------------
        scale = max(
            1.0,
            abs(left_raw),
            abs(right_raw)
        )

        left_norm = left_raw / scale
        right_norm = right_raw / scale

        # ----------------------------------------------------
        # 기본 PWM 계산
        # ----------------------------------------------------
        left_pwm = self.calc_pwm(left_norm)
        right_pwm = self.calc_pwm(right_norm)

        # ----------------------------------------------------
        # 추진기 장착 방향 보정
        #
        # LEFT(CCW)  : 그대로
        # RIGHT(CW)  : PWM 반전
        # ----------------------------------------------------
        self.target_left = self.apply_direction(
            left_pwm,
            LEFT_REVERSED
        )

        self.target_right = self.apply_direction(
            right_pwm,
            RIGHT_REVERSED
        )

        self.get_logger().info(
            f'CMD '
            f'linear={linear:.2f} '
            f'angular={angular:.2f} '
            f'| raw L={left_pwm} R={right_pwm} '
            f'| target L={self.target_left} '
            f'R={self.target_right}'
        )

    # ========================================================
    # 입력값 -> PWM
    # ========================================================

    def calc_pwm(self, val: float) -> int:

        # 거의 0이면 중립
        if abs(val) < 0.01:
            return NEUTRAL_PWM

        delta = bounded_integer(
            round(val * MAX_DELTA),
            -MAX_DELTA,
            MAX_DELTA
        )

        # 전진
        if delta > 0:
            return (
                NEUTRAL_PWM
                + DEADBAND
                + delta
            )

        # 후진
        elif delta < 0:
            return (
                NEUTRAL_PWM
                - DEADBAND
                + delta
            )

        return NEUTRAL_PWM

    # ========================================================
    # PWM 방향 반전
    #
    # 예:
    #
    # 1487 기준
    #
    # 1572 -> 1402
    # 1402 -> 1572
    # ========================================================

    @staticmethod
    def reverse_pwm(us: int) -> int:
        return NEUTRAL_PWM - (us - NEUTRAL_PWM)

    # ========================================================
    # 개별 추진기 방향 설정
    # ========================================================

    def apply_direction(
        self,
        pwm: int,
        reversed_: bool
    ) -> int:

        if reversed_:
            return self.reverse_pwm(pwm)

        return pwm

    # ========================================================
    # 현재 PWM 방향 확인
    # ========================================================

    @staticmethod
    def sign(v: int) -> int:

        if v > NEUTRAL_PWM:
            return 1

        if v < NEUTRAL_PWM:
            return -1

        return 0

    # ========================================================
    # PWM ramp
    # ========================================================

    def ramp(
        self,
        cur: int,
        target: int
    ) -> int:

        # 출력 줄이는 경우 즉시 적용
        if (
            abs(target - NEUTRAL_PWM)
            <=
            abs(cur - NEUTRAL_PWM)
        ):
            return target

        # 출력 증가
        if target > cur:
            return min(
                target,
                cur + STEP_US
            )

        return max(
            target,
            cur - STEP_US
        )

    # ========================================================
    # 20 Hz control loop
    # ========================================================

    def control_loop(self):

        now = time.monotonic()
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

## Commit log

2026-09-03 feat: add thruster node, sketch for B2
2026-09-03 feat: update thruster driver node
2026-09-03 Normalize drive values and update command file path
    Normalize differential drive mixing values to limit between -1.0 and 1.0 before calculating PWM.
2026-09-04 Refactor main.py to simplify actuator control logic
    Removed unused variables and functions related to command parsing and actuator control.
2026-09-04 Refactor Thruster Driver Node for clarity and functionality
    bridge 통신 방식으로 수정
    [thruster_driver_node.py]
2026-09-04 [fix:gcs]: 구글맵 API 키 하드코딩 제거
2026-09-04 Add camera streaming ROS 2 package (surface/underwater cams over HTTP)
    Ported from a separate prototype workspace where this was built and
    tested against synthetic frames. Publishes surface/underwater USB
    camera feeds (OpenCV) as sensor_msgs/Image and re-serves them as MJPEG
    over HTTP on :8000. Not yet reconciled with usv_sensors' existing
    camera_node.py / gps_driver_node.py / water_quality_node.py layout —
    opening this as-is so the team can decide how to fold it in. See
    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
2026-09-04 feat(b2): merge pump and water policy code from PR #7
2026-09-04 [add:camera]: 카메라 노드 추가 및 실행 방식 변경
2026-09-04 [fix:gcs]: 대시보드 화면 비율 조정 및 물고기 뽑기 시스템으로 변경
2026-09-04 [fix]: 카메라 확인 관련 gcs 파라미터 및 readme 수정
2026-09-04 [fix:gcs]: 시작=start, 뽑기=X버튼 확정
2026-09-04 Fix usv_sensors app to run end-to-end on B1 board
    - app.yaml: icon "USV" was not a valid emoji, App Lab rejected it
    - python/main.py: was missing entirely (App Lab requires this entry
    point); added minimal water-quality + GPS console output matching
    the sketch's Bridge.provide("get_water_quality"/"get_gps") handlers
    - sketch.ino: moved struct AdcAccumulator into adc_accumulator.h so it
    is visible at the point the Arduino builder auto-inserts function
    prototypes (was defined after first use, causing a compile error)
    - .gitignore: ignore arduino-app-cli's per-app .cache/ build output
    Verified: app runs, ROS 2 container builds and launches, all
    interface-contract topics (/water_quality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
    [sketch.ino]
2026-09-04 start_sensors.sh: auto-register App Lab symlink on first run
    arduino-app-cli only finds an App by folder name under ~/ArduinoApps/;
    a fresh git clone doesn't live there. Without this, a clean checkout +
    install_autostart.sh fails on the first boot at the exact same
    "app path is not valid" error fixed manually in the previous commit.
    Idempotent, so it's a no-op on boards that already have the symlink.
2026-09-04 start_sensors.sh: use "app restart" instead of "app start"
    "app start" errors with "App Is Running" if this script is re-run
    while a previous invocation's app is still up (e.g. re-running after
    editing the sketch, or a systemd service restart). "app restart"
    handles both the running and not-yet-running case, so the script is
    safe to re-run at any time.
    Reproduced on-device: with usv_sensors already running, re-running
    start_sensors.sh with the old "app start" call failed immediately;
    switching to "app restart" completed cleanly and all interface-
    contract ROS 2 topics came back up.
2026-09-04 [fix:gui] GCS 카메라 호스트 설정을 B1 IP로 수정
2026-09-04 feat: implement PWM thruster control
2026-09-04 refactor: send thruster PWM through UDP gateway
2026-09-06 [fix:gui] 카메라/펌프 패널 정리 및 실제 수질값 연동
    - cameraHost 미설정 시 GCS 자신(localhost)으로 폴백하던 로직 제거, 안내 문구로 대체
    - 오로라 표시를 게임 내부 가짜 waterQuality 대신 실제 센서값(clarity_pct)으로 연동
    (기준값도 water_policy.py와 동일하게 60/40으로 통일)
    - 펌프 제어 패널 UI 개편: 제목 변경, 자동/수동 상태를 신호등 스타일 두 박스로 표시,
    위 미니맵 폭에 맞춰 패널 가로폭 축소
    - GPS 기본 위치를 송도 센트럴파크 실제 좌표로 변경
    - 뽑기 버튼 안내 문구 오타 수정 (Y 버튼 -> X 버튼)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
2026-09-06 [feat:b1,b2]: b1/b2 컨테이너 진입점에 ROS 네트워크 디스커버리 환경변수 설정
    GCS(라즈베리파이)가 서브넷 너머의 B1/B2 ROS 2 노드를 디스커버리할 수 있도록
    usv_sensors, usv_actuators 컨테이너 내부에서 ROS_AUTOMATIC_DISCOVERY_RANGE=SUBNET을
    명시적으로 설정하고 ROS_STATIC_PEERS/ROS_LOCALHOST_ONLY를 해제합니다.
2026-09-06 fix: thrust_driver_node 수정
2026-09-06 [fix:gcs]: GUI 버튼 위치 및 비율 조정
2026-09-06 [fix:gcs]: GCS 상 B1 IP 수정
2026-09-07 feat(b2): add set_pump RPC handler to sketch
    분수 펌프 릴레이를 MCU에서 제어할 수 있도록 set_pump 핸들러를 추가한다.
    actuator_driver_node가 Bridge.notify('set_pump', ...)를 호출하고 있었으나
    스케치에 해당 핸들러가 없어, 명령이 조용히 무시되고 펌프가 동작하지 않았다.
    (notify는 실패해도 예외를 던지지 않아 원인 파악이 어려웠다)
    - PUMP_PIN = D7. 릴레이는 on/off만 하므로 PWM 핀을 쓰지 않는다.
    추진기가 쓰는 D9/D10과 충돌하지 않는다.
    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
2026-09-07 test(b2): add interactive pump test harness
    GUI(조이스틱)와 B1 수질센서 없이 펌프 동작을 검증하는 대화형 스크립트.
    키보드로 조이스틱 버튼과 수질값을 흉내내며, 가짜 값을 실제 ROS 토픽으로
    발행하므로 actuator_driver_node의 로직이 그대로 동작한다.
    검증 가능한 것:
    - 수동(조이스틱) 명령이 자동 제어보다 60초간 우선하는지
    - auto_mode 토글 시 수질 자동 제어가 완전히 멈추는지
    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
2026-09-07 fix(b2): make usv_actuators a valid App Lab app
    App Lab이 usv_actuators를 앱으로 인식하지 못해 목록에 뜨지 않았다.
    arduino-app-cli app list --show-broken-apps로 확인한 오류를 순서대로 해결했다.
    1. icon "USV" is not a valid single emoji
    → app.yaml의 icon을 이모지("🚿")로 교체. App Lab은 아이콘을 이모지
    한 개로만 받는다.
    2. main python file missing from app
    → python/main.py 추가. App Lab은 python/main.py를 요구하는데
    레포에는 scripts/main.py로 있었다. scripts/는 그대로 두고 복사했다.
    이 파일이 있어야 앱 프로세스가 살아있고, 그래야 MCU RPC 핸들러
    등록이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
    [sketch.ino]
2026-09-07 feat(b2): add pump-only launch file
    추진기와 펌프를 서로 다른 보드에 나눠 싣기로 하면서 추가했다.
    actuators.launch.py는 두 노드를 함께 띄우므로, 펌프만 있는 보드에서
    쓰면 추진기 노드가 쓸데없이 떠서 아무도 받지 않는 주소로 UDP를 계속
    쏜다.
    ros2 launch usv_actuators pump.launch.py
    기존 actuators.launch.py는 건드리지 않았다. 추진기 보드는 지금까지
    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
2026-09-07 Revert "Merge pull request #15 from dbswnstj0413/feat/b2-pump-sketch-0907"
    This reverts commit dfd06abb70eab3d6a8c5af047410570d23760e6a, reversing
    changes made to 6690bfd25497807bc2d27a4a5a722052ec527bdf.
    [sketch.ino]
2026-09-09 fix: GCS camera_host를 실제 B1 IP(192.168.0.4)로 수정
    192.168.0.7은 B2(추진기 보드)였음 - 잘못된 IP로 인해 카메라 스트림 접속 불가.
2026-09-10 [fix:camera]: 카메라 node 코드 수정
2026-09-10 [fix:gcs]: 'back'버튼 시, 엔딩에서 처음으로 돌아가는 버튼 추가
2026-09-10 [fix]: 웹에서 카메라 제거 및 readme 수정
2026-09-10 [add:gcs]: google api 작성 수정
2026-09-15 feat(gcs): 펌프 초기 모드를 수동으로 변경 및 자동 모드 시 수동 제어 비활성화
2026-09-15 [feat:gcs]: 미니맵에서 보트/게임맵 좌표계 혼용 버그 수정
2026-09-16 배경음, 효과음, 텍스트 추가
2026-09-16 [feat]: README 수정
2026-09-16 [add:gcs]: 배경음, 효과음, 텍스트 code 추가
2026-09-16 음원 파일 추가
2026-09-16 게임 오디오 추가, 및 게임 설정
2026-09-18 음량조절 및 화면수정
2026-09-21 [fix:gcs] gui 코드 에러 수정
2026-09-21 [add:joy] ramp 함수 적용
2026-09-21 [feat:gui] led 상태 값 추가 및 버튼 수정
2026-09-22 [fix:thruster] 추진기 수정본 코드 업로드
    [thruster_driver_node.py]
2026-09-22 [feat:gcs] 게임 진행 중에만 펌프/자동모드/LED 작동, 종료시 상태 초기화
2026-10-05 [feat:led] B1 LED 무지개(X 버튼) + RPC 수신 멈춤 수정
    - actuator_driver_node: 무지개(/actuator/led_on, set_led_rainbow) 추가
    - actuator_driver_node: GCS 대시보드 LED 켜기(흰색)를 무지개로 처리 (led_on_rainbow 파라미터)
    무지개 상태를 /actuator/led_state로 발행 (대시보드 표시등)
    - actuator_driver_node: 5초마다 LED 상태 재전송 (MCU 재시작 후 자동 복구)
    - usv_sensors: RPClite 0.3.1 복사본(libraries/) 사용 - 수신 버퍼 재동기화 패치
    (잘린 패킷이 버퍼 앞에 남아 MCU 전체가 영구 정지하던 문제)
    - 펌프 코드는 변경 없음
2026-10-05 [feat:led] B1 센서 스케치에 LED(SPI D11) 추가 + 펌프 코드 포함
    - LED: WS2812B 15개 x 2줄, 두 스트립 DIN 모두 D11(SPI2 MOSI)
    SPI 4비트 인코딩(바이트 = 0 1 a 0 0 1 b 0), 색 순서 GRB, 앞뒤 0 패딩 4바이트 + 프레임 간 300us
    NeoPixel(인터럽트 끔) 대신 SPI로 바꿔 Bridge 시리얼 유실 줄임
    - RPC: set_actuator_led(r,g,b), set_led_rainbow(bool) (provide_safe)
    - ※ 펌프 코드 포함: PUMP_PIN(D7, active-low), set_pump, adc_accumulator.h 분리 등은
    B1 펌프 담당자 작업(미커밋 상태였음)을 함께 커밋함
2026-10-08 [feat:gcs] 보트 LED 이펙트(lottie) 추가 + 오로라/퀘스트 UI 조정, 조종 반응성 개선
    - led_effect.json(Lottie 애니메이션)을 lottie-web(canvas 렌더러, 벤더링)로 재생해
    LED on/off에 맞춰 보트 주변에 겹쳐 그림
    - 수질 오로라(red/yellow/green) 크기·투명도 조정 (빨강/노랑만 더 선명하게)
    - 퀘스트/물고기 능력 안내 박스를 호수 화면 우측 하단(사이드바 옆)으로 재배치
    - 대시보드 상태 폴링 200ms로 단축, 미니맵 요청만 1초 쓰로틀로 분리해 조종 반응 지연 감소
    - GPS 미수신 시 dead-reckoning 이동 속도 하향
    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
2026-10-08 [feat:gcs] 상단 남은시간 배너(time.png) 추가, 뽑기/퀘스트 칸 순서 변경, B1 IP 갱신
    - time.png(알파 PNG)로 호수 화면 상단 중앙에 남은시간 배너 추가 - 플레이트 영역만
    잘라 쓰고, 주황 디지털 표시창 자리에 맞춰 시간 텍스트를 겹쳐 그림 (기존 사이드바
    타이머는 유지)
    - 사이드바의 뽑기(150G)/퀘스트 칸 순서를 뽑기 위, 퀘스트 아래로 변경
    - 뽑기 버튼 문구에 (Y) 키 안내 추가
    - gcs_params.yaml: camera_host를 바뀐 B1 보드 IP(192.168.0.6)로 갱신
2026-10-08 [fix:gcs] 추진기 회전 명령 부호 반전, 웹 조이스틱 표시 방향 유지
2026-10-08 [fix:gcs] 게임 시작 시 GPS 기준점 초기화 및 보트 표시 위치 조정
2026-10-08 [feat:gcs] 코드 설정으로 실제 GPS 무시 및 고정 위경도 사용 지원
2026-10-10 Add 3D modeling STL files
    stl 폴더 추가 및 3D 모델링 부품 파일 업로드
    Fusion 360 STL 파일입니다.
    [cover_2.stl, cover_4.stl, dom.stl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]
2026-10-10 [docs:media] 센트럴파크 활동 사진과 시연 영상 추가
2026-10-10 [docs:readme] 발표자료 기반 설계 및 현장 테스트 기록 추가
2026-10-10 [fix:gcs] GPS 미니맵 분리 및 웹 보트 설정·주석 정리
2026-10-10 [docs:media] 수면·수중 카메라 표시 이미지 추가
2026-10-10 [fix:system] 보드 구성 반영 및 미사용 상태 표시 정리
2026-10-12 [docs:readme] 영문 README 추가 및 언어 전환 링크 연결
